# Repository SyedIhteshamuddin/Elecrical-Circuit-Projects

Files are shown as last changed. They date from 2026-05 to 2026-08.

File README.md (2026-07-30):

# Electrical Engineering Portfolio 

Welcome! This repository documents my hands-on engineering projects completed while exploring electronics, embedded systems, circuit design, and PCB development.

My goal is to build practical engineering skills through designing, simulating, documenting, and improving real hardware projects rather than only studying theory.

---

## Current Projects

### ATmega328P-Smart-Assistive-Navigator PCB
⭐ *Latest Project*

This project documents the complete design of a custom two-layer printed circuit board (PCB) for an ATmega328P-based assistive navigation hardware platform.

### SAN - (Smart Assistive Navigator)
An Arduino-based prototype that assists visually impaired users by detecting nearby obstacles and providing feedback using ultrasonic sensors and vibration/audio alerts.

### Adaptive Smart Light System
An automatic lighting system that adjusts LED brightness according to ambient light levels using an LDR sensor.

### Smart Gas Leakage System
A gas monitoring and alert system that detects gas levels and responds using LEDs, LCD messages, and a buzzer alarm.

More projects and experiments will be added over time as I continue learning.

---
## Skills Demonstrated

Throughout these projects, I have gained practical experience in:

### Electronics
- Circuit Analysis
- Embedded Systems
- Sensor Interfacing
- Hardware Documentation
- PCB Design
- KiCad
- Schematic Capture
- PCB Layout
- Component Placement
- Manual Routing
- DRC Verification
- Gerber Generation

### Programming
- Arduino
- Embedded C++
- Firmware Development

### Engineering Tools
- MATLAB
- Autodesk Tinkercad
- KiCad

---
## Project Files

Each project folder usually contains:

- `.ino` file → Arduino code for the project
- `.mp4` file → working demo/simulation video
- `.png` file → circuit design screenshot
- `bom.csv` → components used in the circuit
- `README.md` → explanation of how the project works

---
## Certificates & Learning

This repository also includes a few engineering-related certificates and learning records connected to:

- MITx Certificate
-Circuit Analysis
-Electronics

- MATLAB
-automation
-embedded systems
-engineering software/tools

- Altium PCB Design Course
 -PCB Designing
 -PCB Manufacturing
 -PCB Simulation

Check Certifications Folder for more details.
---

## Why I Started This Repository

I created this repository to document my progress while exploring electronics and embedded systems.

Right now I’m mainly focused on:
- sensor-based systems
- automation concepts
- Arduino projects
- circuit simulation
- learning how different components interact in a complete system

I’ll continue updating this repository as I build more projects and improve my understanding.

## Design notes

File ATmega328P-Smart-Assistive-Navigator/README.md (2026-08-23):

# ATmega328P Smart Assistive Navigator PCB

<p align="center">
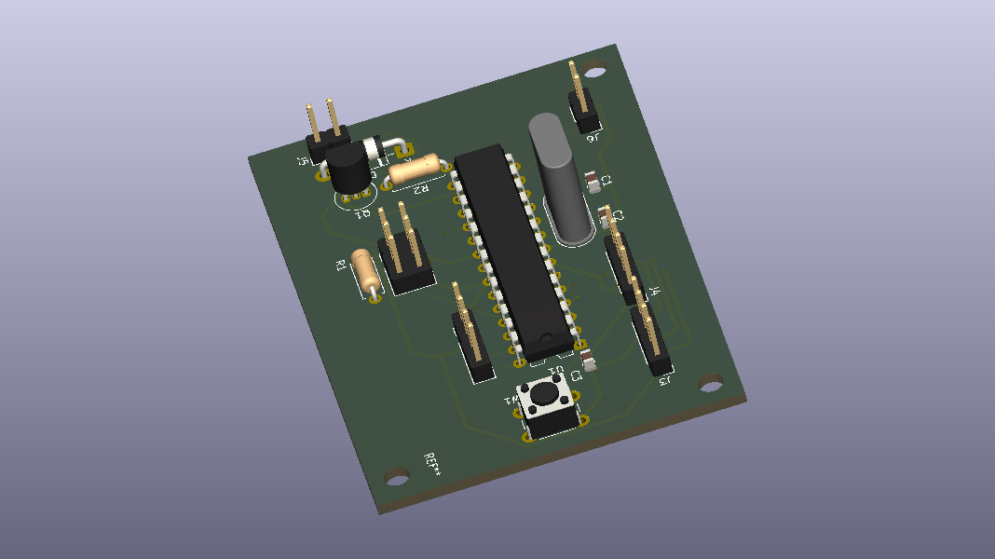
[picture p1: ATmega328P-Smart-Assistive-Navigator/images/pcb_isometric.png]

</p>






</p>
Designed as a personal hardware engineering project to learn the complete PCB development workflow from schematic capture to fabrication-ready manufacturing files using KiCad.

---

# Project Overview

This project documents the complete design of a custom two-layer printed circuit board (PCB) for an ATmega328P-based assistive navigation hardware platform.

The primary objective was to gain practical experience with the complete PCB design workflow rather than relying on development boards such as the Arduino Uno. The design process included schematic capture, footprint assignment, PCB layout, routing, electrical verification, design rule checking (DRC), and fabrication file generation using KiCad.

Although the board has not been physically manufactured or tested, the project successfully demonstrates a complete PCB design workflow suitable for fabrication.

---

# Gallery

## Design Files

<table align="center">
<tr>
<td align="center" width="50%">

### Schematic

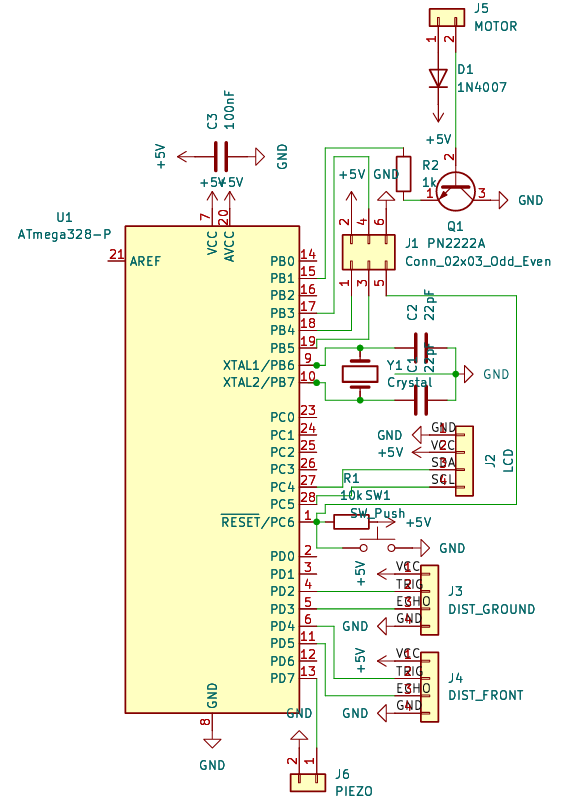
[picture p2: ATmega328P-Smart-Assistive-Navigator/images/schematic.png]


</td>

<td align="center" width="50%">

### PCB Layout

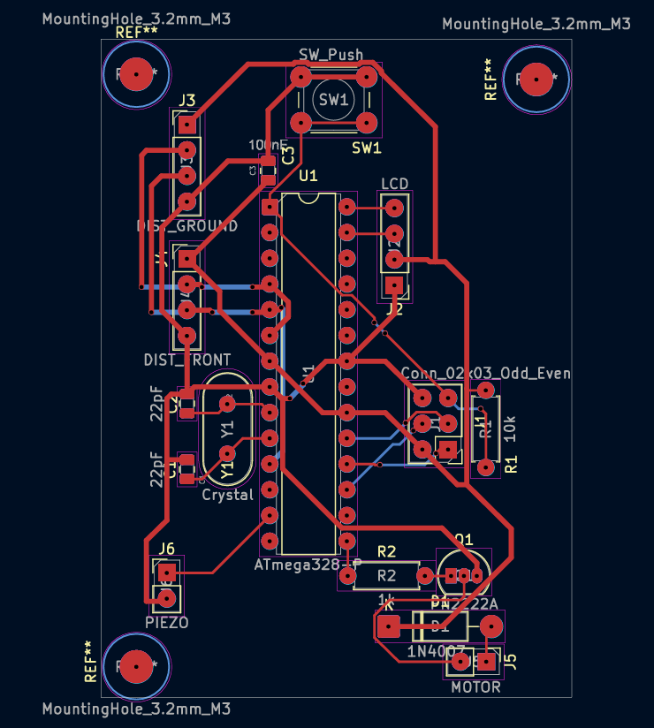
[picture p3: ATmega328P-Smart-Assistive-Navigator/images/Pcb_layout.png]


</td>
</tr>
</table>

---

## Final PCB

<table align="center">
<tr>

<td align="center" width="33%">

### Front View

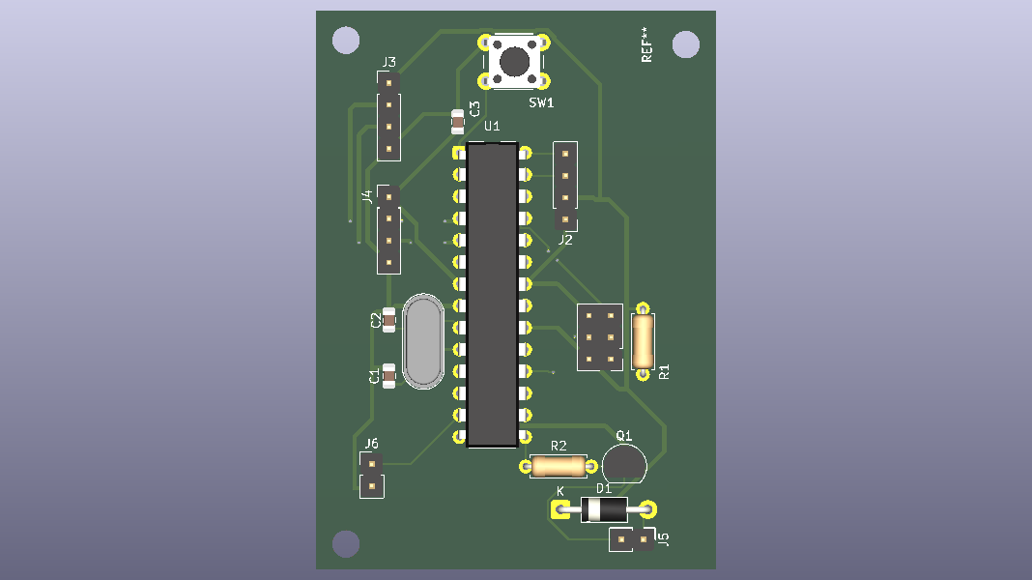
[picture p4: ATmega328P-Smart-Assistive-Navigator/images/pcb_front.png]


</td>

<td align="center" width="33%">

### Back View

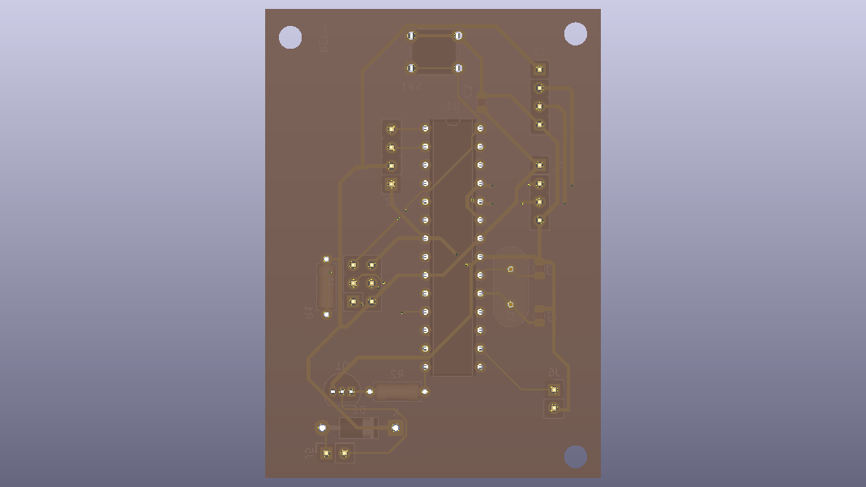
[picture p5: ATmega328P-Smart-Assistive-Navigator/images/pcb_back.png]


</td>

<td align="center" width="33%">

### Isometric View



</td>

</tr>
</table>

---

# Objectives

- Learn professional PCB design using KiCad
- Design a custom PCB around the ATmega328P microcontroller
- Understand schematic capture and PCB layout
- Learn component placement strategies
- Perform manual PCB routing
- Verify the design using Design Rule Checks (DRC)
- Generate fabrication-ready Gerber and drill files

---

# System Features

- ATmega328P microcontroller
- Dual HC-SR04 ultrasonic sensor interfaces
- I²C LCD display interface
- Piezo buzzer output
- PN2222A transistor-based vibration motor driver
- External 16 MHz crystal oscillator
- AVR ISP programming header
- Reset push button
- Decoupling capacitor
- Two-layer PCB layout

---

# Hardware Components

| Component | Purpose |
|---|---|
| ATmega328P | Main microcontroller |
| HC-SR04 ×2 | Obstacle detection |
| 16 MHz Crystal | System clock |
| 22 pF Capacitors | Crystal load capacitors |
| 100 nF Capacitor | Power supply decoupling |
| PN2222A | Motor driver transistor |
| 1N4007 | Flyback protection diode |
| Piezo Buzzer | Audio feedback |
| I²C LCD Header | Display interface |
| AVR ISP Header | Programming interface |
| Push Button | Reset switch |

---

## PCB Specifications

| Parameter | Value |
|---|---|
| PCB Software | KiCad 10 |
| Board Type | Custom PCB |
| PCB Layers | 2 |
| Routing | Manual |
| Mounting Style | Through-Hole (THT) |
| Microcontroller | ATmega328P-PU |
| Board Verification | Design Rule Check (DRC) Passed |
| Manufacturing Files | Gerber + Drill Files Generated |
| PCB Status | Fabrication-Ready Design |

Copper Thickness: 1 oz (standard fabrication assumption)

Minimum Trace Width:
0.25 mm

Minimum Clearance:
0.20 mm

## Design Workflow

This project followed a complete PCB development workflow:

1. Requirement definition
2. Schematic capture
3. Component footprint assignment
4. PCB floorplanning
5. Manual component placement
6. Manual two-layer routing
7. Design Rule Check (DRC)
8. Fabrication file generation
9. 3D verification
10. Documentation

---

## Design Validation

| Check | Status |
|---|---|
| Electrical Rule Check (ERC) | Completed |
| Design Rule Check (DRC) | Passed |
| PCB Routing | Completed |
| Gerber Files | Generated |
| Drill Files | Generated |
| Ready for Fabrication | Yes (Design Only) |
| Physical Assembly | Not Performed |

> **Note:** This project has not been physically manufactured or electrically validated. "Ready for Fabrication" indicates that the design files were successfully generated and verified using KiCad's design checks.

---
## Repository Structure
```text
ATmega328P-Smart-Assistive-Navigator-PCB
│
├── README.md
│
├── hardware
│   ├── SAN PCB.kicad_pcb
│   ├── SAN PCB.kicad_sch
│   └── SAN PCB.kicad_pro
│
├── firmware
│   └── SAN.ino
│
├── fabrication
│   ├── Fabrication_Files.zip
│   └── README.md
│
├── bom
│   └── BOM.csv
│
├── docs
│   ├── SAN PCB.pdf
│   └── SAN PCB PrintView.pdf
│
└── images
    ├── schematic.png
    ├── pcb_layout.png
    ├── pcb_front.png
    ├── pcb_back.png
    └── pcb_isometric.png
```

---

# Challenges Faced

During the development of this project I encountered several practical PCB design challenges including:

- Selecting appropriate footprints
- Crystal oscillator placement
- Decoupling capacitor positioning
- PCB routing optimization
- Managing trace intersections
- Using both copper layers effectively
- Resolving Design Rule Check (DRC) violations
- Preparing fabrication outputs

Working through these issues provided valuable hands-on experience with the PCB design process.

---
## Design Decisions

Several design decisions were made during the PCB layout to improve reliability and follow standard PCB design practices.

- Placed the 100 nF decoupling capacitor close to the ATmega328P power pins to reduce supply noise.
- Positioned the 16 MHz crystal oscillator adjacent to the microcontroller to minimize clock trace length.
- Used dedicated 22 pF load capacitors for crystal stability.
- Included an ISP programming header for firmware uploading and debugging.
- Used a PN2222A transistor to safely drive the vibration motor from the microcontroller.
- Added a flyback diode (1N4007) across the motor output to protect the transistor from inductive voltage spikes.
- Routed signal traces manually to reduce unnecessary crossings and improve readability.
- Performed Design Rule Checks (DRC) before generating fabrication files.
  
---

# Lessons Learned

Through this project I developed practical experience with:

- PCB schematic design
- Component footprint selection
- Two-layer PCB layout
- Manual routing techniques
- PCB design constraints
- Design verification
- Manufacturing file generation
- Professional engineering documentation
- Tradeoffs between routing simplicity and board compactness
- Importance of component placement before routing

---
## Skills Demonstrated

Through this project I gained practical experience in:

- PCB Design using KiCad
- Electronic Schematic Capture
- Footprint Selection
- Component Placement
- Manual PCB Routing
- Two-Layer PCB Design
- Design Rule Verification (DRC)
- Gerber File Generation
- Bill of Materials (BOM) Creation
- Hardware Documentation
- Basic Embedded Hardware Design
-  PCB Manufacturing Documentation
---

# Future Improvements

Future versions of this project could include:

- Physical PCB fabrication
- Hardware assembly and testing
- USB programming interface
- Improved component placement
- Reduced PCB dimensions
- Surface-mount (SMD) version
- Power supply optimization

---

# Author

**[Syed Ihteshamuddin]**

High School Student | Aspiring Electrical Engineer

Areas of Interest:

- Electrical Engineering
- Embedded Systems
- PCB Design
- Hardware Development

GitHub: https://github.com/syedihteshamuddin

---

> This repository documents a personal learning project completed to develop practical skills in embedded hardware and PCB design.

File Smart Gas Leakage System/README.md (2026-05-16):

# Smart Gas Leakage System

This project is an Arduino + Tinkercad based gas monitoring and alert system built while learning embedded systems and automation concepts.

The system continuously monitors gas levels using a gas sensor and responds with different warning stages based on gas concentration.

---

## Features

- Real-time gas monitoring
- Multi-level gas detection
- SAFE / WARNING / DANGER indication
- LCD status display
- LED alert indicators
- Buzzer alarm during dangerous gas levels
- Serial monitor live sensor values

---

## Components Used

- Arduino Uno
- Gas Sensor
- LCD Display (16x2 I2C)
- LEDs
- Buzzer
- Resistors
- Breadboard
- Tinkercad Circuits
Smart Gas Leakage System
---

## How The System Works

The gas sensor continuously reads surrounding gas concentration levels.

Depending on the sensor value:

- SAFE level → Green LED turns ON
- WARNING level → Yellow LED turns ON
- DANGER level → Red LED + buzzer alarm activate

The LCD display shows:
- current system status
- live gas sensor value

This creates a simple simulation of an automated gas leakage warning system.

---

## Threshold Levels

| Gas Value | System Status |
|---|---|
| Below 307 | No Gas Detected |
| 307 - 499 | SAFE |
| 500 - 699 | WARNING |
| 700+ | DANGER |

---

## What I Learned

While building this project, I learned:

- basics of gas sensors
- analog sensor readings
- threshold-based system logic
- LCD interfacing
- buzzer integration
- multi-output embedded system behavior
- how monitoring systems react to environmental conditions

I also improved my understanding of how sensors, outputs, and decision-making logic work together in embedded systems.

---

## Future Improvements

Some improvements I may explore later:

- GSM alert system
- IoT monitoring
- mobile notifications
- automatic ventilation system
- real hardware implementation

---

## Project Preview



---

## Built Using

- Arduino
- Tinkercad Circuits
- Arduino Blocks + C++

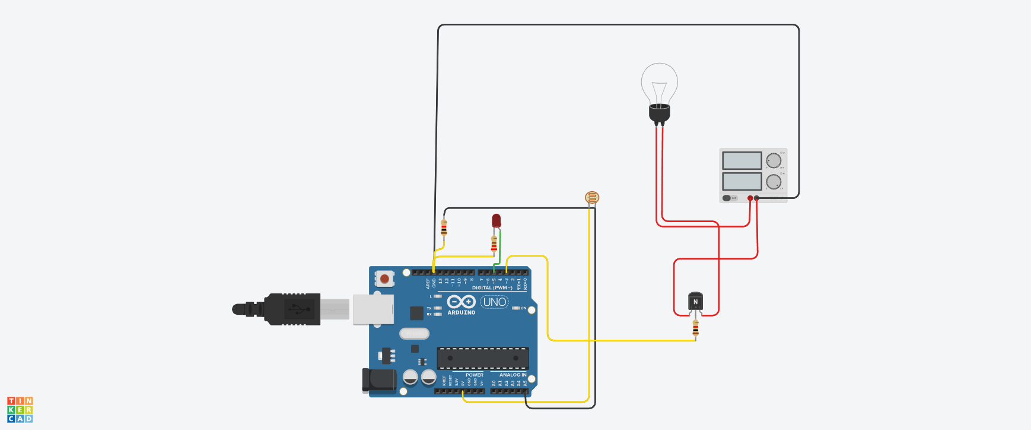
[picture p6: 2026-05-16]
Adaptive Smart Light System/Adaptive Smart Street Light System.png

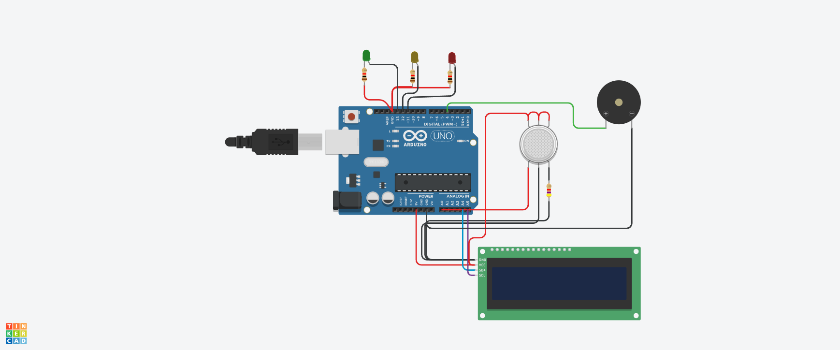
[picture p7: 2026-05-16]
Smart Gas Leakage System/Smart Gas Leakage System.png

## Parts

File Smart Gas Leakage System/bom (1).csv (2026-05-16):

Name | Quantity | Component
U1 | 1 | Arduino Uno R3
GAS1 | 1 | Gas Sensor
R23 | 1 | 4.7 kΩ Resistor
D11 | 1 | Green LED
D12 | 1 | Yellow LED
D13 | 1 | Red LED
R24, RGa, R26 | 3 | 1 kΩ Resistor
U2 | 1 | MCP23008-based, 32 (0x20) LCD 16 x 2 (I2C)
PIEZO1 | 1 | Piezo

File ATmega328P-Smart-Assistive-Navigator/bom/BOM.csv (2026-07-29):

Item | Reference | Quantity | Component | Value/Part Number | Package | Description
1 | U1 | 1 | Microcontroller | ATmega328P-PU | DIP-28 | 8-bit AVR microcontroller
2 | Y1 | 1 | Crystal | 16 MHz | HC-49S | Clock source for ATmega328P
3 | C1 | 1 | Ceramic Capacitor | 22 pF | Radial THT | Crystal load capacitor
4 | C2 | 1 | Ceramic Capacitor | 22 pF | Radial THT | Crystal load capacitor
5 | C3 | 1 | Ceramic Capacitor | 100 nF | Radial THT | Power supply decoupling capacitor
6 | R1 | 1 | Resistor | 10 kΩ | Axial THT | ATmega328P reset pull-up resistor
7 | R2 | 1 | Resistor | 1 kΩ | Axial THT | Base current limiting resistor for transistor
8 | Q1 | 1 | NPN Transistor | PN2222A | TO-92 | Motor driver transistor
9 | D1 | 1 | Diode | 1N4007 | DO-41 | Flyback protection diode
10 | SW1 | 1 | Tactile Push Button | 6x6 mm | THT | Reset push button
11 | J1 | 1 | AVR ISP Header | 2x3 Pin | THT | ISP programming connector
12 | J2 | 1 | LCD Header | 1x4 Pin | THT | I2C LCD interface header
13 | J3 | 1 | Sensor Header | 1x4 Pin | THT | Ground ultrasonic sensor connector
14 | J4 | 1 | Sensor Header | 1x4 Pin | THT | Front ultrasonic sensor connector
15 | J5 | 1 | Motor Connector | 1x2 Pin | THT | Motor output connector
16 | J6 | 1 | Piezo Connector | 1x2 Pin | THT | Piezo buzzer connector

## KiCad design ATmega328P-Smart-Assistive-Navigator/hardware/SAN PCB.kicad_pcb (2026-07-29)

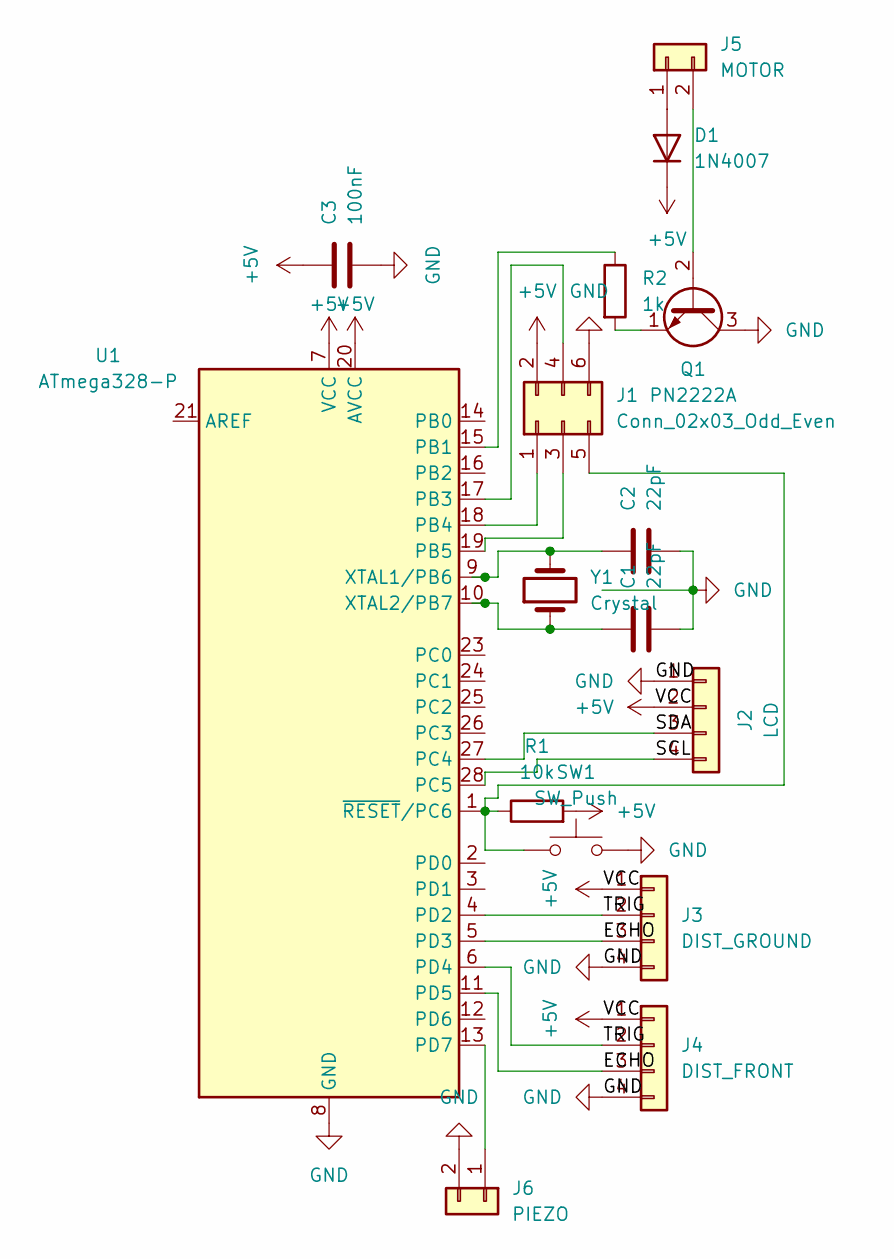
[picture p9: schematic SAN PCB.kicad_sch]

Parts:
C1, C2: 22pF; C_0805_2012Metric
C3: 100nF; C_0805_2012Metric
D1: 1N4007; D_DO-41_SOD81_P10.16mm_Horizontal
J1: Conn_02x03_Odd_Even; PinHeader_2x03_P2.54mm_Vertical
J2: LCD; PinHeader_1x04_P2.54mm_Vertical
J3: DIST_GROUND; PinHeader_1x04_P2.54mm_Vertical
J4: DIST_FRONT; PinHeader_1x04_P2.54mm_Vertical
J5: MOTOR; PinHeader_1x02_P2.54mm_Vertical
J6: PIEZO; PinHeader_1x02_P2.54mm_Vertical
Q1: PN2222A; TO-92_Inline
R1: 10k; R_Axial_DIN0207_L6.3mm_D2.5mm_P7.62mm_Horizontal
R2: 1k; R_Axial_DIN0207_L6.3mm_D2.5mm_P7.62mm_Horizontal
SW1: SW_Push; SW_PUSH_6mm
U1: ATmega328-P; DIP-28_W7.62mm
Y1: Crystal; Crystal_HC49-U_Vertical

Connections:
+5V: C3.1, D1.1 (K), J1.2, J2.2 (VCC), J3.1, J4.1, R1.2, U1.7 (VCC), U1.20 (AVCC)
/ECHO: J3.3, J4.3, U1.5 (PD3), U1.11 (PD5)
/SCL: J2.4 (SCL), U1.28 (PC5)
/SDA: J2.3 (SDA), U1.27 (PC4)
/TRIG: J3.2, J4.2, U1.4 (PD2), U1.6 (PD4)
GND: C1.2, C2.2, C3.2, J1.6, J2.1 (GND), J3.4, J4.4, J6.2, Q1.3 (C), SW1.2, U1.8 (GND), U1.22 (GND)
unnamed: D1.2 (A), J5.1
unnamed: J1.1, U1.18 (PB4)
unnamed: J1.3, U1.19 (PB5)
unnamed: J1.4, U1.17 (PB3)
unnamed: J1.5, R1.1, SW1.1, U1.1 (~RESET/PC6)
unnamed: J5.2, Q1.2 (B)
unnamed: J6.1, U1.13 (PD7)
unnamed: Q1.1 (E), R2.2
unnamed: R2.1, U1.15 (PB1)
unnamed: C2.1, U1.9 (XTAL1/PB6), Y1.2
unnamed: C1.1, U1.10 (XTAL2/PB7), Y1.1

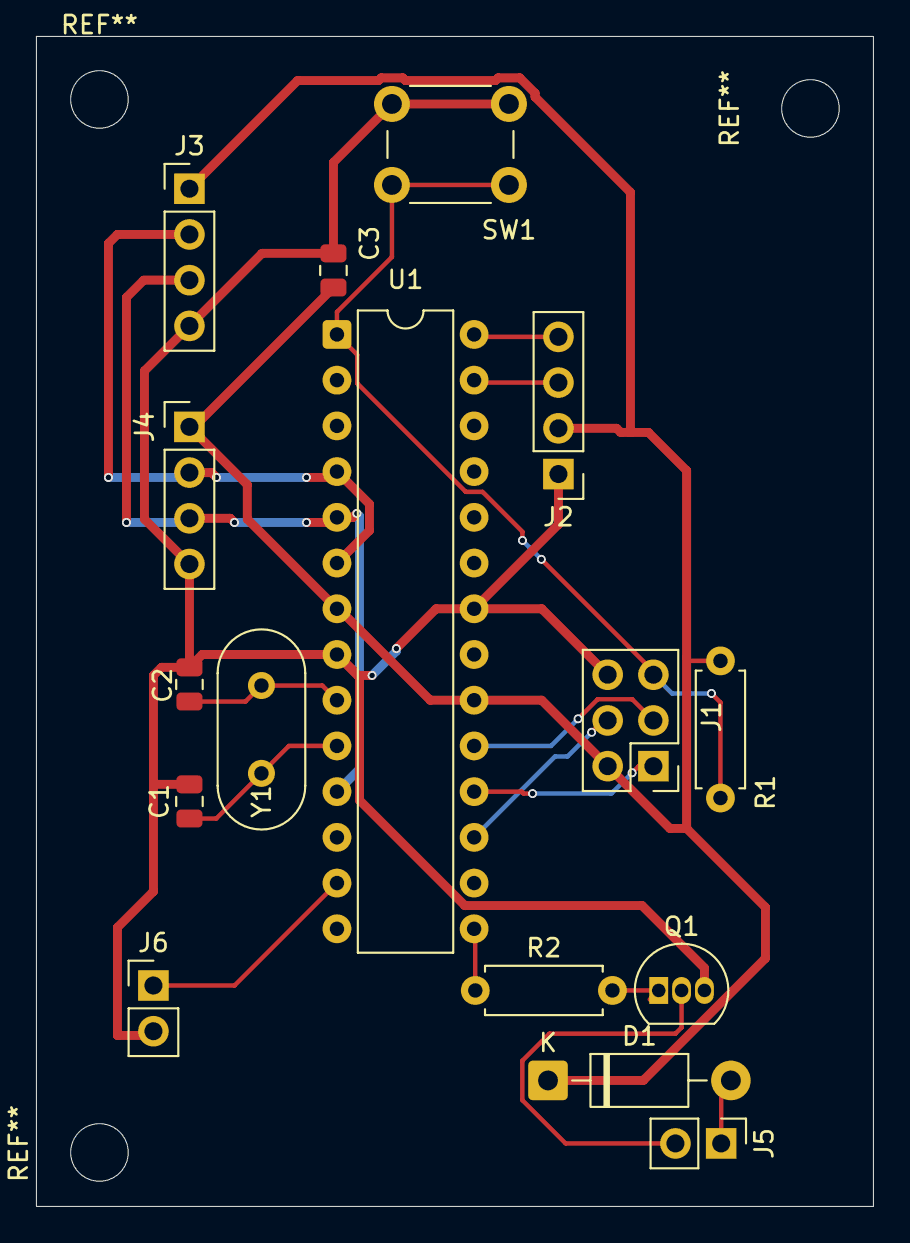
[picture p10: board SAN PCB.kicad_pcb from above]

Board: 2 copper layers, 46.5 x 65.0 mm, 16 parts (0 on the bottom side), 17 nets.

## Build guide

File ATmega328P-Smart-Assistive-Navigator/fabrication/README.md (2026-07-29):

## Fabrication Files

The fabrication package contains:

- Gerber files
- NC Drill files

These files were generated using KiCad 10 and are suitable for submission to standard PCB manufacturers such as JLCPCB or PCBWay.

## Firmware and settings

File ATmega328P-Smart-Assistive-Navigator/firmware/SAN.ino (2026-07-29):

/*
===============================================================================
                     SMART ASSISTIVE NAVIGATOR (SAN)
===============================================================================

Firmware Version : 1.0 RC1
Author           : Syed Ihteshamuddin
Platform         : Arduino UNO (ATmega328P)

Project Overview
----------------
Smart Assistive Navigator (SAN) is an embedded assistive mobility system
designed to improve obstacle awareness and drop-off detection for visually
impaired users.

The system continuously monitors the environment using dual ultrasonic sensors,
processes measurements through a robust filtering algorithm, classifies hazards
using a finite state machine with hysteresis, and provides intuitive haptic and
auditory feedback in real time.

===============================================================================
Hardware Configuration
===============================================================================

Microcontroller
---------------
• Arduino UNO R3

Sensors
-------
• HC-SR04 Ultrasonic Sensor (Front Obstacle Detection)
• HC-SR04 Ultrasonic Sensor (Ground / Drop Detection)

Output Devices
--------------
• 16×2 LCD Display (I²C Backpack)
• Vibration Motor
• Piezo Buzzer

===============================================================================
System Features
===============================================================================

✓ Dual Ultrasonic Navigation
✓ Obstacle Detection
✓ Stair / Drop Detection
✓ Median-Based Sensor Filtering
✓ Sensor Failure Recovery
✓ Finite State Machine with Hysteresis
✓ Non-blocking Alert Engine
✓ Intelligent LCD Update Manager
✓ Boot Self-Test Routine
✓ State Transition Alerts
✓ Serial Debug Interface

===============================================================================
Navigation States
===============================================================================

SAFE          : Normal walking condition
NEAR          : Obstacle approaching
CRITICAL      : Immediate obstacle warning
DROP          : Stair / Edge detected
SENSOR_ERROR  : Sensor communication failure

===============================================================================
Pin Configuration
===============================================================================

Front Ultrasonic
----------------
Trigger : D3
Echo    : D2

Ground Ultrasonic
-----------------
Trigger : D5
Echo    : D4

Output Devices
--------------
Motor  : D9
Buzzer : D11

LCD
---
I²C Backpack

===============================================================================
Copyright
===============================================================================

Developed as an independent embedded systems project for educational,
engineering portfolio, and assistive technology research purposes.

===============================================================================
*/

#include <Adafruit_LiquidCrystal.h>

Adafruit_LiquidCrystal lcd(7);

// ---------------- PIN DEFINITIONS ----------------

const byte FRONT_TRIG = 3;
const byte FRONT_ECHO = 2;

const byte GROUND_TRIG = 5;
const byte GROUND_ECHO = 4;

const byte MOTOR_PIN = 9;
const byte BUZZER_PIN = 11;

//---------------- THRESHOLDS ----------------

const int SAFE_DISTANCE = 150;
const int SAFE_EXIT     = 160;

const int CRITICAL_DISTANCE = 75;
const int CRITICAL_EXIT     = 85;

const int DROP_DISTANCE = 22;
const int DROP_EXIT     = 14;

// ---------------- STATES ----------------

enum NavigationState
{
  SAFE,
  NEAR,
  CRITICAL,
  DROP,
  SENSOR_ERROR
};

NavigationState currentState = SAFE;
NavigationState previousState = SENSOR_ERROR;

// ---------------- DISTANCES ----------------

int frontDistance = 0;
int groundDistance = 0;

// ---------------- SENSOR CACHE ----------------

int lastFrontDistance = 150;
int lastGroundDistance = 10;

byte frontFailCount = 0;
byte groundFailCount = 0;

const byte MAX_SENSOR_FAILURES = 5;

byte dropDetectCount = 0;
byte dropClearCount = 0;

const byte DROP_CONFIRM_COUNT = 3;
const byte DROP_CLEAR_COUNT = 3;


//--------------------------------------------------
// LCD CACHE
//--------------------------------------------------

int oldFront = -999;
int oldGround = -999;

NavigationState oldLCDState = SENSOR_ERROR;

// --------------------------------------------------
// ALERT ENGINE VARIABLES
// --------------------------------------------------

unsigned long alertTimer = 0;
unsigned long lcdTimer = 0;

bool alertOutput = LOW;

int alertOnTime = 0;
int alertOffTime = 0;

int buzzerFrequency = 0;


//---------- GLOBAL OUTPUT CONTROL VARIABLES------------



long readUltrasonic(byte trigPin, byte echoPin)
{
  pinMode(trigPin, OUTPUT);

  digitalWrite(trigPin, LOW);
  delayMicroseconds(2);

  digitalWrite(trigPin, HIGH);
  delayMicroseconds(10);

  digitalWrite(trigPin, LOW);

  pinMode(echoPin, INPUT);

  long duration = pulseIn(echoPin, HIGH, 30000);

  if(duration==0)
      return -1;

  return duration;
}

// --------------------------------------------------

int getDistanceCM(byte trig, byte echo)
{
    long duration = readUltrasonic(trig, echo);

    if (duration == -1)
        return -1;

    int distance = duration * 0.01723;

    if (distance < 2 || distance > 300)
        return -1;

    return distance;
}

// --------------------------------------------------
// SENSOR ACQUISITION & FILTERING
// --------------------------------------------------

int medianDistance(byte trig, byte echo)
{
    int sample[3];
    int validCount = 0;

    // Collect three readings
    for(int i = 0; i < 3; i++)
    {
        int d = getDistanceCM(trig, echo);

        if(d != -1)
        {
            sample[validCount++] = d;
        }

        delay(2);
    }

    // No valid readings
    if(validCount == 0)
        return -1;

    // One valid reading
    if(validCount == 1)
        return sample[0];

    // Two valid readings
    if(validCount == 2)
        return (sample[0] + sample[1]) / 2;

    // Three valid readings -> median
    if(sample[0] > sample[1])
    {
        int t = sample[0];
        sample[0] = sample[1];
        sample[1] = t;
    }

    if(sample[1] > sample[2])
    {
        int t = sample[1];
        sample[1] = sample[2];
        sample[2] = t;
    }

    if(sample[0] > sample[1])
    {
        int t = sample[0];
        sample[0] = sample[1];
        sample[1] = t;
    }

    return sample[1];
}
//--------------------------------------------------
// Reads and validates ultrasonic sensor data.
//--------------------------------------------------
void readSensors()
{
    int newFront = medianDistance(FRONT_TRIG, FRONT_ECHO);
    int newGround = medianDistance(GROUND_TRIG, GROUND_ECHO);

    //---------------- FRONT SENSOR ----------------

    if(newFront == -1)
    {
        frontFailCount++;

        if(frontFailCount >= MAX_SENSOR_FAILURES)
            frontDistance = -1;
        else
            frontDistance = lastFrontDistance;
    }
 else
{
    frontFailCount = 0;
    frontDistance = newFront;
    lastFrontDistance = newFront;
}
    //---------------- GROUND SENSOR ----------------

    if(newGround == -1)
    {
        groundFailCount++;

        if(groundFailCount >= MAX_SENSOR_FAILURES)
            groundDistance = -1;
        else
            groundDistance = lastGroundDistance;
    }
  else
{
    groundFailCount = 0;
    groundDistance = newGround;
    lastGroundDistance = newGround;
}
  }

//--------------------------------------------------
// NAVIGATION STATE MACHINE (HYSTERESIS)
//--------------------------------------------------

// Determines navigation state using hysteresis.

void determineState()
 {
    if(frontDistance == -1 || groundDistance == -1)
{
    currentState = SENSOR_ERROR;
    return;
}

    switch(currentState)
    {

        //---------------- SAFE ----------------

        case SAFE:

            if(groundDistance > DROP_DISTANCE)
{
    dropDetectCount++;

    if(dropDetectCount >= DROP_CONFIRM_COUNT)
    {
        currentState = DROP;
        dropDetectCount = 0;
    }
}
else
{
    dropDetectCount = 0;

    if(frontDistance < CRITICAL_DISTANCE)
        currentState = CRITICAL;
    else if(frontDistance < SAFE_DISTANCE)
        currentState = NEAR;
}
           

            break;


        //---------------- NEAR ----------------

        case NEAR:

            if(groundDistance > DROP_DISTANCE)
            {
                currentState = DROP;
            }
            else if(frontDistance < CRITICAL_DISTANCE)
            {
                currentState = CRITICAL;
            }
            else if(frontDistance > SAFE_EXIT)
            {
                currentState = SAFE;
            }

            break;


        //---------------- CRITICAL ----------------

        case CRITICAL:

            if(groundDistance > DROP_DISTANCE)
            {
                currentState = DROP;
            }
            else if(frontDistance > CRITICAL_EXIT)
            {
                currentState = NEAR;
            }

            break;


        //---------------- DROP ----------------

       case DROP:

    if(groundDistance < DROP_EXIT)
    {
        dropClearCount++;

        if(dropClearCount >= DROP_CLEAR_COUNT)
        {
            dropClearCount = 0;

            if(frontDistance < CRITICAL_DISTANCE)
                currentState = CRITICAL;
            else if(frontDistance < SAFE_DISTANCE)
                currentState = NEAR;
            else
                currentState = SAFE;
        }
    }
    else
    {
        dropClearCount = 0;
    }

    break;


        //---------------- SENSOR ERROR ----------------

        case SENSOR_ERROR:

            currentState = SAFE;

            break;
    }
}
//--------------------------------------------------
// LCD USER INTERFACE
//--------------------------------------------------

// Updates LCD only when displayed values change.

void updateLCD()
{
    char buffer[17];

    // ---------- Front Distance ----------

    if(frontDistance != oldFront)
{
    lcd.setCursor(0,0);

    if(frontDistance == -1)
    {
        lcd.print("F:---cm ");
    }
    else
    {
        sprintf(buffer,"F:%3dcm", frontDistance);
        lcd.print("        ");
        lcd.setCursor(0,0);
        lcd.print(buffer);
    }

    oldFront = frontDistance;
}
    // ---------- Ground Distance ----------

    if(groundDistance != oldGround)
{
    lcd.setCursor(0,1);

    if(groundDistance == -1)
    {
        lcd.print("G:---cm ");
    }
    else
    {
        sprintf(buffer,"G:%3dcm", groundDistance);
        lcd.print("        ");
        lcd.setCursor(0,1);
        lcd.print(buffer);
    }

    oldGround = groundDistance;
}
  

    // ---------- Navigation State ----------

    if(currentState != oldLCDState)
    {
        lcd.setCursor(10,0);
        lcd.print("      ");        // erase old state
        lcd.setCursor(10,0);

        switch(currentState)
        {
            case SAFE:
                lcd.print("SAFE");
                break;

            case NEAR:
                lcd.print("NEAR");
                break;

            case CRITICAL:
                lcd.print("STOP");
                break;

            case DROP:
                lcd.print("DROP");
                break;

          case SENSOR_ERROR:
    lcd.print("ERROR");
    break;
        }

        oldLCDState = currentState;
    }
}
// --------------------------------------------------

void serialDebug()
{

    Serial.print("Front : ");

    Serial.print(frontDistance);

    Serial.print(" cm | Ground : ");

    Serial.print(groundDistance);

    Serial.print(" cm | State : ");

    switch(currentState)
    {

      case SAFE:

        Serial.println("SAFE");

      break;

      case NEAR:

        Serial.println("NEAR");

      break;

      case CRITICAL:

        Serial.println("CRITICAL");

      break;

      case DROP:

        Serial.println("DROP");

      break;

      case SENSOR_ERROR:

        Serial.println("ERROR");

      break;
      
    
    }

}

void playTransitionAlert()
{
    switch(currentState)
    {
        case SAFE:

            tone(BUZZER_PIN,800);
            delay(25);
            noTone(BUZZER_PIN);

            break;


        case NEAR:

            digitalWrite(MOTOR_PIN,HIGH);
            delay(40);
            digitalWrite(MOTOR_PIN,LOW);

            break;


        case CRITICAL:

            for(byte i=0;i<2;i++)
            {
                tone(BUZZER_PIN,1500);
                delay(20);
                noTone(BUZZER_PIN);
                delay(15);
            }

            break;


        case DROP:

            digitalWrite(MOTOR_PIN,HIGH);
            tone(BUZZER_PIN,2200);

            delay(120);

            digitalWrite(MOTOR_PIN,LOW);
            noTone(BUZZER_PIN);

            break;


        case SENSOR_ERROR:

            for(byte i=0;i<3;i++)
            {
                tone(BUZZER_PIN,400);
                delay(15);
                noTone(BUZZER_PIN);
                delay(10);
            }

            break;
    }
}

// --------------------------------------------------
// ALERT ENGINE
// --------------------------------------------------

// Generates vibration and buzzer alert patterns.

void updateAlerts()
{
    unsigned long now = millis();
  
  if(currentState != previousState)
{
    alertOutput = LOW;
    alertTimer = 0;
}

    switch(currentState)
    {

        //---------------- SAFE ----------------

        case SAFE:

            digitalWrite(MOTOR_PIN, LOW);
            noTone(BUZZER_PIN);
            alertOutput = LOW;
            alertTimer = millis();   // reset timer
            return;

        //---------------- SENSOR ERROR ----------------

        case SENSOR_ERROR:

            alertOnTime = 150;
            alertOffTime = 150;
            buzzerFrequency = 300;

            break;

        //---------------- NEAR ----------------

        case NEAR:

            alertOnTime = 250;
            alertOffTime = 750;
            buzzerFrequency = 900;

            break;

        //---------------- CRITICAL ----------------
      case CRITICAL :
alertOnTime = 120;
alertOffTime = 120;
buzzerFrequency = 1500;

            break;

        //---------------- DROP ----------------

        case DROP:

            alertOnTime = 500;
            alertOffTime = 200;
            buzzerFrequency = 2200;

            break;
    }

    if(alertOutput)
    {
        if(now-alertTimer>=alertOnTime)
        {
            alertTimer=now;

            alertOutput=LOW;

            digitalWrite(MOTOR_PIN,LOW);

            noTone(BUZZER_PIN);
        }
    }
    else
    {
        if(now-alertTimer>=alertOffTime)
        {
            alertTimer=now;

            alertOutput=HIGH;

            digitalWrite(MOTOR_PIN,HIGH);

            tone(BUZZER_PIN,buzzerFrequency);
        }
    }
}

//--------------------------------------------------
// BOOT SELF TEST
//--------------------------------------------------

void bootSelfTest()
{
    lcd.clear();

    lcd.setCursor(0,0);
    lcd.print("SYSTEM CHECK");

    lcd.setCursor(0,1);
    lcd.print("LCD......OK");

    delay(250);

    lcd.setCursor(0,1);
    lcd.print("FRONT....");

    if(getDistanceCM(FRONT_TRIG, FRONT_ECHO) != -1)
        lcd.print("OK");
    else
        lcd.print("FAIL");

    delay(250);

    lcd.setCursor(0,1);
    lcd.print("GROUND...");

    if(getDistanceCM(GROUND_TRIG, GROUND_ECHO) != -1)
        lcd.print("OK");
    else
        lcd.print("FAIL");

    delay(250);

    lcd.setCursor(0,1);
    lcd.print("MOTOR....OK");

    delay(200);

    lcd.setCursor(0,1);
    lcd.print("BUZZER...OK");

    tone(BUZZER_PIN,1200);
    delay(100);
    noTone(BUZZER_PIN);

    delay(200);

    lcd.clear();

    lcd.setCursor(0,0);
    lcd.print(" SYSTEM READY");

    lcd.setCursor(0,1);
    lcd.print("Have a Safe Walk");

    delay(600);

    lcd.clear();
}

// --------------------------------------------------

void setup()
{

    Serial.begin(9600);
  
    Serial.println("===== BOOT =====");

    lcd.begin(16,2);

    pinMode(MOTOR_PIN,OUTPUT);

    pinMode(BUZZER_PIN,OUTPUT);

    lcd.clear();
  
    oldFront = -999;
  
    oldGround = -999;
  
    oldLCDState = SENSOR_ERROR;

    lcd.setCursor(0,0);

    lcd.print(" Smart Assistive ");

    lcd.setCursor(0,1);

    lcd.print(" Navigator ");

    delay(1500);

    lcd.clear();
  
    bootSelfTest();

}

// --------------------------------------------------

void loop()

{
  readSensors();


    determineState();
 
  if(currentState != previousState)
{
    playTransitionAlert();
}
  

    if (millis() - lcdTimer >= 100)
{
    lcdTimer = millis();
    updateLCD();
}


    updateAlerts();


    serialDebug();


    previousState = currentState;


    delay(50);  
}  

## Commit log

2026-05-13 Rename .brd to Adaptive Smart Street Light System.brd
    [Adaptive Smart Street Light System.brd]
2026-07-30 Rename SAN PCBschmmView.pdf to schematic.png
2026-07-30 Rename SAN PCB PrintView.pdf to pcb_layout.png
2026-07-30 Rename SAN PCB 3d_Front.png to pcb_front.png
2026-07-30 Rename SAN PCB 3d_Back.png to pcb_back.png
2026-07-30 Rename SAN PCB 3d_Isometric.png to pcb_isometric.png
2026-07-30 Rename schematic.png to Schematic.png
